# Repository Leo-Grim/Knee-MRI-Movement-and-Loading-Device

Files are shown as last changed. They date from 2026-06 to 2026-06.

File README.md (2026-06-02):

# Repo Overview

This Repository contains all files needed for the construction and assembly of the Device. References are contained in the Final Report.

# Knee-MRI-Movement-and-Loading-Device

A compact, passive, MRI-compatible knee motion and loading device designed for use inside standard closed-bore 3 T MRI scanners.
This project was developed as an Imperial College London Bioengineering group project to enable controlled knee flexion and compressive loading during MRI. The aim is to support imaging of load-dependent knee behaviour, such as cartilage deformation, altered joint contact mechanics, and meniscal extrusion, which may not be visible during conventional unloaded supine MRI.

## Project Overview
Conventional knee MRI is usually performed with the patient lying supine, with the knee unloaded and close to full extension. While this gives high-quality anatomical images, it does not represent the mechanical conditions experienced by the knee during movement or weight-bearing.

This device addresses that limitation by providing:

- Controlled knee flexion using a passive notch-lock mechanism
- Compressive loading through a resistance-band footplate system
- MRI-compatible construction using non-ferromagnetic materials
- Operation inside a standard closed-bore 3 T scanner
- Patient-controlled adjustment using guiding ropes

The prototype is intended as a research platform for future loaded and flexed knee MRI studies.

## Key Features

- Passive mechanical actuation
- No motors, electronics, pneumatics, or ferromagnetic components
- Compatible with closed-bore 3 T MRI environments
- Constructed from PLA and HDPE
- Adjustable knee flexion through discrete notch positions
- Resistance-band-based axial loading
- Low-cost fabrication using FDM 3D printing and CNC machining
- Modular design for future refinement and replication

## Device Concept

The device consists of two main subsystems:

### 1. Movement System

The movement system controls knee flexion. It uses a hinged leg plate and a notch-lock base plate to hold the leg at predefined angles. The user can adjust the knee angle by pulling guide ropes while lying inside the scanner.

### 2. Loading System

The loading system applies compressive force through the foot. A footplate moves along rails against resistance bands, generating a displacement-dependent load. Loading is applied by pushing the footplate to its end position before imaging.

## Materials

The prototype was manufactured from MRI-compatible polymer materials:

- **PLA**: used for 3D-printed components, including hinge parts, rails, notches, backplate, and footplate components
- **HDPE**: used for CNC-machined plate sections due to its flexibility, impact resistance, and machinability

No ferromagnetic, electronic, or closed conductive components are used in the current prototype.

## Fabrication

The prototype was fabricated using:

- Fused deposition modelling 3D printing
- CNC machining of HDPE sheets
- Resistance bands for passive loading
- Polymer-based fasteners and mechanical components where possible

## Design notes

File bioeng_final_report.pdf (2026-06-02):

# DESIGN AND DEVELOPMENT OF AN MRI-COMPATIBLE KNEE MOTION AND LOADING DEVICE

Group ScansOperator

## Department of Bioengineering

## Imperial College London

A Project Report Submitted in Partial Fulfilment of the

Bioengineering Group Project

Supervisor:
Dr P Lally

Department of Bioengineering p.lally@imperial.ac.uk

Word count: 4863
April, 2026

## Jacob Beeson Leonardo Grimaldi Ben Jones Sheena Ling Belle Mok Amy Li Tayeb Tadlaoui Hannah Wei

Abstract

Conventional knee Magnetic Resonance Imaging (MRI) is performed under static, unloaded conditions, limiting detection of load-dependent pathology such as meniscal extrusion, altered cartilage contact mechanics, and early osteoarthritis (OA) progression. Existing dynamic and weight-bearing MRI approaches address this limitation but are constrained by reduced image quality in open-bore systems, or by the complexity, cost, and coil incompatibility of motorised and pneumatic devices designed for closed-bore scanners.
This project aimed to design, fabricate, and validate a compact, passive, MRI-compatible device capable of delivering controlled knee flexion and compressive loading within a standard closed-bore 3 T scanner. The device was constructed entirely from non-ferromagnetic thermoplastics (polylactic acid and high-density polyethylene) using fused deposition modelling and computer numerical control machining. Validation comprised finite element analysis, experimental force-displacement characterisation of a resistance-band loading mechanism, phantom MRI at 3 T, and healthy volunteer usability trials.
The prototype achieved a bench-validated flexion range of 0-117° across five discrete notch-lock positions, with an in-bore range of 0-74° confirmed at 3 T, nearly doubling the ∼40° reported in previous closed-bore devices. The configurable force output of 86-271 N spans the sub-weight-bearing regime in which MRI-detectable cartilage changes have been demonstrated. Phantom imaging confirmed no device-induced artefacts. Volunteer trials also indicated high comfort and perceived safety.
With participant validation and clinical testing, this platform could support earlier detection of load-dependent knee pathology currently undetectable under conventional static imaging.

## 1 Introduction

### 1.1 Clinical and Biomechanical Context

Knee pathologies are a major source of pain, reduced mobility, and long-term disability worldwide, particularly in ageing populations [1]. Osteoarthritis (OA) is the most prevalent musculoskeletal (MSK) disorder, affecting over 500 million individuals globally and most commonly involving the knee [2]. Meniscal tears, ligament injuries, malignancies, and osteomyelitis also contribute to the clinical burden [3].
Mechanical behaviour of the knee is central to the onset and progression of these pathologies. As the largest synovial joint, the knee operates under complex, load-dependent conditions in which contact stresses, joint alignment, and kinematics vary with motion. During routine activities, compressive forces can exceed multiple times body weight (BW), with load distribution mediated by cartilage and meniscal function [4].

### 1.2 MRI for Knee Assessment and Its

Fundamental Limitation

Magnetic Resonance Imaging (MRI) is the primary modality for evaluating soft tissue in the knee due to its high-resolution, multi-planar imaging capability without ionising radiation [5]. It enables imaging of cartilage, menisci, ligaments, and subchondral bone, and thus is widely used in diagnosis and disease monitoring. However, standard MRI is performed with the patient supine, joint unloaded, and typically near full extension. While this configuration optimises image quality and reproducibility, it imposes a crucial limitation: the joint is imaged in a mechanically altered state [6].

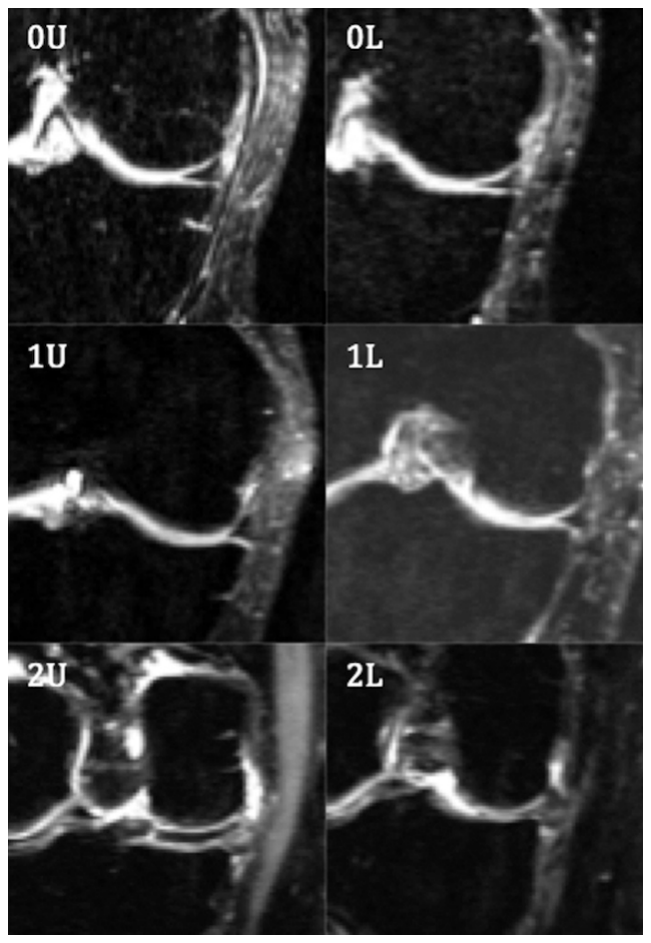
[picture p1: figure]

Figure 1: Coronal MRI of medial menisci under unloaded (U) and loaded (L) conditions in subjects with both increasing radiographic severity (Kellgren–Lawrence score 0–2, top to bottom) and medial meniscal extrusion under loading across all subjects.
Adapted from Patel et al. [7].

As a result, clinically relevant features such as cartilage deformation, tibiofemoral contact mechanics, and meniscal extrusion are either diminished or absent [8], as illustrated in Figure 1, where differences between unloaded and loaded conditions become apparent. This reflects a limitation of the acquisition method rather than imaging resolution. Consequently, an unloaded MRI provides an anatomically accurate but mechanically incomplete representation of the joint, limiting its sensitivity to early or load-dependent pathology.

### 1.3 Existing Approaches to Dynamic Knee

MRIs

To overcome this limitation, dynamic and weight-bearing MRI techniques have been developed to capture joint behaviour under load or motion [4]. These approaches include axial loading systems, which apply compressive forces to the knee, and dynamic imaging systems that induce controlled joint movement during acquisition.
These methods have demonstrated clear benefits, including the ability to reveal load-dependent changes in cartilage contact, joint alignment, and meniscal displacement. However, their clinical applicability is constrained by trade-offs between physiological realism, image quality, and system integration.
Open-bore MRI systems have been widely used in such studies for their larger geometry, which accommodates upright or partially weight-bearing postures and external loading apparatus (Figure 2). However, they operate at lower field strengths (0.2–1.0 T), reducing signalto-noise ratio (SNR) and spatial resolution compared to high-field (1.5–3.0 T) closed-bore scanners [9, 10], limiting detection of subtle structural changes in early disease.

Figure 2: Open-bore MRI setup for weight-bearing joint imaging. Adapted from Draper et al. [11].

Closed-bore dynamic MRI systems preserve image quality but face other limitations. External rigs are bulky and difficult to integrate within the confined bore, while motorised actuation introduces electromagnetic interference (EMI) and ferromagnetic safety risks, and pneumatic systems require complex external infrastructure [12]. The Brisson et al. device [13] (Figure 3) achieved guided flexion up to ∼40° via a beltdriven motorised pneumatic system, but required external motor hardware, a custom gearbox, and flexible surface coils in place of a standard knee coil.

Figure 3: Example of a motorised closed-bore knee motion and loading device. Left: 3D rendering of the device assembly. Right: the device in a 3 T scanner with a subject. Reproduced from Brisson et al. [13] under CC BY-NC-ND 4.0 licence.

Even compact axial loading devices for supine imaging provide only partial solutions, replicating compressive loading but lacking controlled joint motion across a range of flexion. Existing approaches therefore either sacrifice imaging quality, mechanical fidelity, or clinical integration.

### 1.4 Engineering Constraints in

Closed-Bore MRI

The development of any device intended for use within an MRI environment is constrained by strict safety, material, and geometric requirements. Strong static magnetic fields, time-varying gradients, and radiofrequency (RF) energy impose limitations on both material selection and actuation strategies.
According to established safety guidance [14], ferromagnetic materials must be excluded due to projectile and torque risks, while conductive materials must be minimised to avoid RF-induced heating and imaging artefacts. These constraints favour the use of polymer-based materials and non-magnetic components, but introduce challenges in achieving sufficient mechanical strength and durability.
Beyond material requirements, closed-bore MRI systems impose significant geometric limitations, restricting available space to a bore diameter of 60–70 cm. Any device must therefore be compact, compatible with coil placement, and allow for patient positioning. Electrically driven systems are generally unsuitable due to EMI and safety concerns [12]. Consequently, mechanical systems provide a more viable approach, but must be capable of delivering controlled, repeatable motion without active feedback or external control systems.
These combined constraints define a tightly bounded design space in which mechanical functionality, MRI compatibility, and clinical usability must be simultaneously satisfied.

### 1.5 Research Gap, Objectives and

Hypothesis

Despite the development of dynamic and weight-bearing techniques, no widely adopted solution currently exists. Such an ideal system should enable controlled and repeatable knee motion and loading within a standard high-field closed-bore MRI environment without compromising image quality, safety, or simplicity.
This study addresses this gap through the design and development of a compact, passive, mechanical, MRI-compatible knee loading and motion device intended to enable diagnostic imaging under physiologically relevant loading within a closed-bore scanner. Functional daily activities require less than 90° of knee flexion for level walking, and 90-120° for stair negotiation and chair use [15], with tibiofemoral compressive forces ranging from ∼107% BW (∼735 N) during bilateral stance to over ∼346% BW (∼2,376 N) during stair descent for a 70 kg individual [16]. Reproducing such ambulatory forces within a closed-bore scanner is neither practical nor necessary for diagnostic purposes, as MRI-detectable tissue changes have been demonstrated at substantially lower, sub-weight-bearing loads. Sub-weight-bearing loads of ∼50% BW (∼350 N at 20° flexion) represent the most widely validated loading protocol, producing significant decreases in cartilage T1ρ (spin-lattice relaxation in the rotating frame) and T2 (spin-spin relaxation) times, both sensitive to early compositional changes in cartilage matrix, and increased meniscal extrusion at 3 T [17, 18]. In vivo T1ρ changes have been detected at loads as low as 20 kg (∼196 N) in the patellofemoral joint [19], and ex vivo compartmental loading has revealed significant cartilage responses from 73.5 N [20]. A device operating within this sub-weight-bearing regime could therefore be sufficient to elicit diagnostically relevant tissue responses without approaching full ambulatory loads.
Regarding flexion, the range over which diagnostically useful images can be acquired within a closed-bore scanner is more restricted, as increasing flexion displaces the knee from the magnetic isocentre and reduces image quality. Existing closed-bore devices have been limited to ∼40° due to the geometric constraints of a typical 60–70 cm bore diameter [13]. This study ideally targets a flexion range of 0 to 90°, subject to the geometric constraints of the scanner.
The specific objectives are, therefore, to:
1. Develop a passive mechanical system enabling controlled knee flexion over an ideal range of 0-90° with discrete angular positioning [9, 21].
2. Deliver compressive loading within the sub-weight-bearing regime, with forces approaching or exceeding the ∼200 N threshold at which in vivo T1ρ changes have been demonstrated [19], ideally reaching the ∼350 N (50% BW) level used in most published loading protocols [17, 18, 22].
3. Quantify | the | repeatability | of | the | force-
displacement response.
4. Ensure full compliance with MRI safety and material constraints.
It is hypothesised that a passive, non-ferromagnetic mechanical system can achieve controlled and repeatable knee motion within MRI constraints without introducing imaging artefacts or compromising patient safety. Validation of this hypothesis would demonstrate the feasibility of integrating such a device into clinical studies aimed at assessing load-dependent knee biomechanics.

## 2 Methods

### 2.1 Concept Development, Selection and

Design

The design was divided into two subsystems, movement and loading, to allow parallel development and to achieve defined objectives.

### 2.1.1 Movement System Design

Figure 4: Design of the movement component, with leg-plate configurations for different knee angles, 0° (left), 45° (centre), 90° (right).

A patient-controlled mechanism was selected, incorporating guiding ropes, a leg-plate, and leg-plate stoppers. This enabled user adjustment, repeatable stable positioning at predefined angles, minimised the need for radiographer intervention, and maintained MRI compatibility. Device flexion angle was defined as the angle between the thigh-plate and calf-plate axes at the hinge joint (Figure 5), corresponding anatomically to the angle between the femoral and tibial axes when the limb rests along the respective plates.

Figure 5: Definition of the device flexion angle. The blue line represents the thigh-plate axis, the red line represents the calf-plate axis, and the yellow arc indicates the flexion angle at the knee.

### 2.1.2 Loading System Design

Figure 6: CAD design of the loading component; red boxes indicate attachment points for resistance bands, red arrows indicate direction of footplate travel and foot pushing (increasing left to right)

A resistance-band loading mechanism was selected as a lightweight, non-ferromagnetic solution for generating force. As shown in Figure 6, the system consisted of a footplate, through which compressive load was transmitted along the lower limb, and a backplate, which functioned as structural support. Resistance bands were anchored between the fixed baseplate and the footplate, generating a displacement-dependent force that increased with footplate travel.

Figure 7: Open-source planetary gear wheels used for Loading System.

The footplate was translated by eight wheels that rolled along rails within the backplate, using an open-source planetary gear wheel design, shown in Figure 7, to minimise friction between moving components, a difficulty noted in previous mechanical systems [23].

### 2.1.3 Final Design

Figure 8: Integration of the loading and movement systems. The red arrow indicates the direction of footplate travel, and the yellow arrow indicates the direction of rope pulling to increase angle.

To integrate the subsystems, the loading component was mounted at the distal end of the leg-plate, shown in Figure 8. Imaging would occur at maximum footplate displacement of 20 cm, corresponding to contact between the footplate and backplate. Scans would be repeated at predefined knee angles using the usercontrolled movement system for sequential image acquisition.

### 2.2 Material Selection

Parameter | Value | Unit
Layer orientation | Flat | –
Raster angle | 0/90 | °
Layer height | 0.1 | mm
Infill density | 15% | –
Infill pattern | Rectilinear | –

Table 1: Key 3D printing FDM process parameters used.

Polymer-based materials were selected to ensure MRI safety [14], and evaluated against processing complexity and mechanical reliability across the required range of motion.
PLA was selected due to its dimensional stability during fused deposition modelling (FDM) [24]. The anisotropic properties of FDM-made parts were accounted for through component orientation with FDM parameters defined in Table 1. Alternative materials were eliminated due to processing complexity and limited accessibility.
HDPE was selected due to its impact resistance, flexibility, and cost [25]. HDPE was purchased in sheet form, enabling simple and reliable fabrication. Secondary sustainability benefits included PLA’s renewable origin [26] and HDPE’s recyclability [27].

### 2.3 CAD Modelling, Iterative Design, and

Prototype Fabrication

The movement and loading systems were developed through an iterative computer-aided design (CAD), simulation, and fabrication process. Finite element analysis (FEA) and physical prototyping were conducted in parallel on load-bearing components, with high-stress regions identified and refined. Iterative updates were applied to improve structural integrity and usability.

### 2.3.1 Fabrication of Movement Component

Figure 9: Earlier iteration of the movement component CAD model that informed the final fabrication strategy.

The movement component was manufactured using a combination of FDM and computer numerical control (CNC) machining. The hinge joints, base plate notches, and rails were manufactured through FDM in PLA, allowing rapid iteration of the more complex components. The larger plate sections were CNCmachined from HDPE sheets.

### 2.3.2 Fabrication of Loading Component

Figure 10: CAD models of Backplate with screw holes shown (left) and Footplate (right), before attachment and inclusion of wheels and other components.

The loading component was manufactured by FDM in PLA. It consisted of two sub-assemblies: the backplate and the footplate, shown in Figure 10. The final backplate and footplate designs could each be printed as single parts on a 3D printer (FDM). The final design also included screw holes for attachment to the movement component.

### 2.4 Risk Assessment and Safety

Considerations

A structured risk assessment conducted on key risks, their likelihood, severity, and mitigation strategies, is summarised in Table 2.

Risk | Description | L | S | Mitigation | Contingency
MRI Safety | Component not MRI-safe | Low | High | Non-ferromagnetic ma-terial selection, magnet testing of components, device-only MRI dry run | Remove or replace unsafe components
Mechanical Failure | Structural failure or insufficient force | Med | Med | FEA with safety factors, incremental loading during testing, spare parts avail-able | Redesign and reprint com-ponents
Patient Safety | Pain or unsafe knee motion | Med | High | Patient-controlled motion, motion limits, padding and adjustable supports | Reduce motion range; use patient-driven movement only
Schedule | Delays in fabrica-tion or testing | Med | Med | Built-in time buffers, paral-lel task allocation, backup fabrication options | Scope reduction if required

Table 2: Risk assessment for device development. L = Likelihood, S = Severity; ratings: Low, Medium (Med), High.

### 2.5 Operation of Device inside the

Scanner

Figure 11: Series of images displaying the initial position of the device (left), insertion of foot and pushing against footplate (centre), and pulling ropes to change knee angle (right).

Device operation is patient-controlled and supported by a radiographer using the scanner communication system. A user manual was developed for radiographer training and user operation (Appendix F). During imaging, the patient lies supine, with one leg positioned on the movement component, the foot placed against the loading footplate. Compressive load is applied by pushing the footplate to its maximum displacement (in contact with the baseplate), after which an MRI is acquired at predefined knee angles. Between scans, the patient adjusts the flexion angle by pulling the guiding ropes until reaching the next notch-lock position, then reapplies load before the next acquisition (Figure 11).

### 2.6 Testing and Validation Methodology

This validation process aimed to determine whether the device could generate and sustain controlled and repeatable compressive loads.

### 2.6.1 Computational Analysis

All components were evaluated through computational analysis using FEA in Ansys Mechanical [28]. Deformation and stress analyses were performed to identify critical stress concentrations across the assembly under load (Appendix C). The mesh was subsequently refined in high-stress regions to improve simulation accuracy and better distribute the load across the structure. Insights from each analysis were used to inform iterative improvements to the CAD models, allowing structural weaknesses to be addressed before fabrication.

### 2.6.2 Resistance Band Testing

Figure 12: Digital dynamometer with hook used to analyse resistance band force profile (left), with unfolded (centre) and folded (right) resistance band configurations.

Force-displacement tests were used to characterise the mechanical behaviour of the resistance-band loading system and assess its suitability for force generation. A digital dynamometer was used to record force at controlled displacements of the resistance band under two configurations: unfolded and folded, shown in Figure 12. A 1.1 mm, 30 cm Internal Diameter Latex resistance band was used. The unfolded configuration represented a single band segment, while the folded configuration represented the band doubled back to produce a shorter load path and higher resistance. For the unfolded configuration, displacement was increased in 1 cm increments (1 − 15 cm). For the folded configuration, displacement was increased in 0.5 cm increments (0.5−7.5 cm). Five measurements were taken at each displacement. The data were then analysed, and the two configurations were compared using the code in Appendix E.

### 2.6.3 MRI In-Bore Testing

The device was tested in a 3 T MRI scanner using a water-filled phantom positioned at the knee location. A large 4-channel flexible coil was placed around the phantom and device to replicate the intended imaging configuration (Figure 13). Acquisition parameters are summarised in Table 3. The device was scanned at 0° to confirm the absence of imaging artefacts, and the maximum in-bore flexion angle was determined by advancing the movement component through its notch-lock positions until bore geometry prevented further flexion.

Parameter | Value
Scanner | Siemens Magnetom Verio 3 T
Sequence | PD TSE (sagittal)
Acquisition time | 3 min 34 s
Voxel size | 0.6 × 0.6 × 3.0 mm
TR / TE | 5300 / 36.0 ms
Flip angle | 150°
Turbo factor | 10
Slices | 35
FOV | 240 mm
Coil | Large 4-channel flex coil

Table 3: MRI acquisition parameters for in-bore phantom testing.

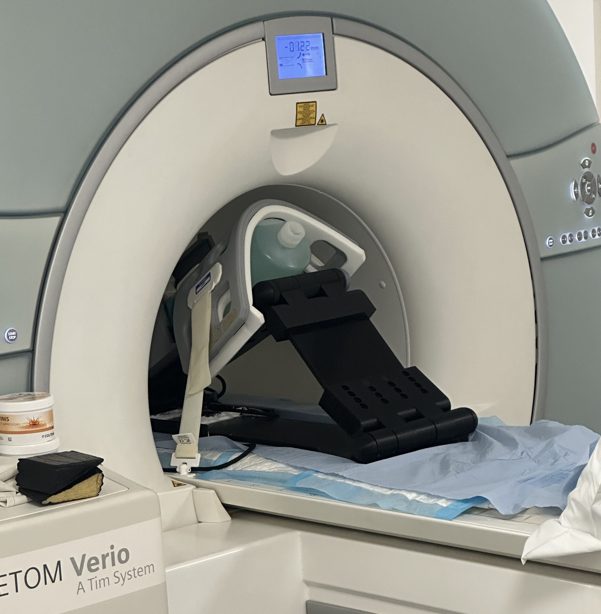
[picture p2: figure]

Figure 13: Device positioned within the Siemens Magnetom Verio 3 T scanner bore at the maximum in-bore flexion angle (74°), with the water-filled phantom and large 4-channel flexible coil in place.

## 3 Results

### 3.1 Finite Element Analysis

Property | PLA | HDPE | Unit
Density | 1240 | 970 | kg/m³
Young’s Modulus | 3.5 | 1.1 | GPa
Poisson’s Ratio | 0.36 | 0.45 | –
Yield Strength | 50 | 23.6 | MPa
UTS | 65 | 45 | MPa
Shear Modulus | 1.29 | 0.75 | GPa

Table 4: Material properties of PLA and HDPE at 25°C (UTS is Ultimate Tensile Strength).

FEA was performed on each prototype iteration of both the loading and movement components, using PLA and HDPE material properties (Table 4).

### 3.1.1 Loading Component

62.4 N was applied to the load-bearing components, corresponding to the single unfolded band configuration at the tested displacement range, then doubled to give a safety factor of 2. Higher-stiffness band configurations (up to 271 N projected, Table 6) were therefore not explicitly simulated and would require additional FEA verification. The resulting stress distributions and deformation profiles were used to identify specific regions of weakness.

### 3.1.2 Movement Component

Downward forces were applied as the primary load case, set at ∼314 N, 100% greater than the average weight of the human leg (∼16 kg, 157 N).

Figure 14: Ansys simulations of stress of final design under a downward force of 314 N.

Early prototypes exhibited excessive deflection and localised stress under load, prompting redesign and a transition to HDPE in some components. FEA of the final design yielded a peak von Mises stress of 3.42 MPa and maximum deformation of 0.36 mm under 314 N loading, both well within HDPE’s yield strength of 26 MPa. Hinge joints were redesigned to prevent structural failure under load, and for the final design, a stopper was added to the end of the calf plate to support the peak stress seen in the final design in Figure 14.

### 3.2 Angular Positioning

The movement component achieved stable positioning at five flexion angles, corresponding to the notch-lock positions along the base plate. Angles were determined from triplicate measurements on photographs of the device at each notch-lock position using ImageJ [29], with a measurement uncertainty of ±1°. The measured on-bench angles were 0°, 37°, 74°, 93°, and 117° (Figure 15), spanning from full extension to maximum flexion of 117°.

Figure 15: Composite overlay of the movement component at all device angles, from 0°-117°.

### 3.3 Force-Displacement Analysis of

Resistance Bands

### 3.3.1 Force-Displacement Response

For the loading mechanism, force-displacement behaviour was characterised in unfolded and folded configurations.

Figure 16: Mean force-displacement response of the resistance band in unfolded and folded configurations, shown with 95% confidence intervals (CI).

The folded band produced higher force than the unfolded band across the tested range, as seen in Figure 16 consistent with increased effective stiffness in the doubled-band configuration.

### 3.3.2 Stiffness and Model Fitting

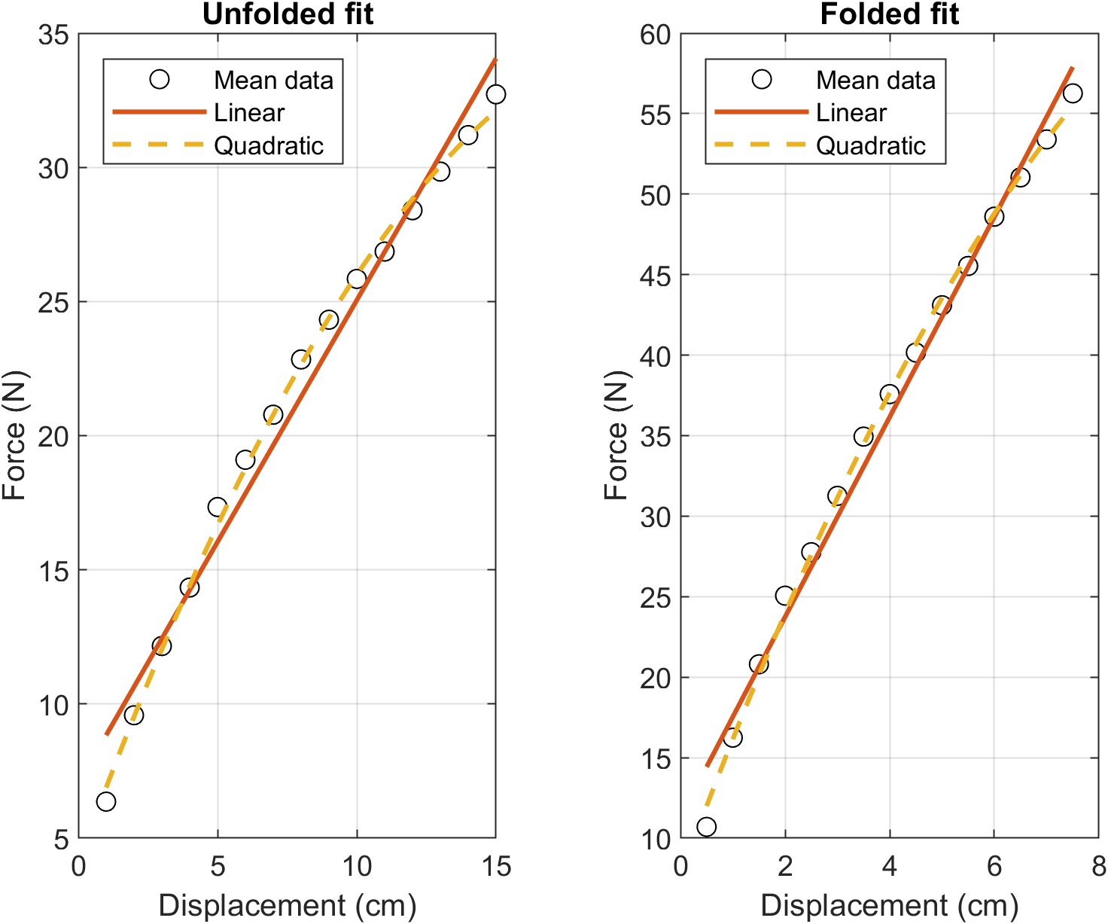
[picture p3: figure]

Figure 17: Linear and quadratic fits to the mean force-displacement data for unfolded and folded resistance band configurations.

Parameter | Unfolded | Folded
Max mean force (N) | 32.72 | 56.26
Max displacement (cm) | 15.0 | 7.5
Global stiffness (N/cm) | 1.802 | 6.211
Best model | Quadratic | Quadratic
Adjusted R² | 0.9976 | 0.9977
CV (High-Low) | 13.8-4.56% | 15.97-2.46%
AIC (High-Low) | 50.07-17.57 | 57.84-32.93

Table 5: Summary of key force-displacement results for the resistance band configurations, CV is the Coefficient of Variation and AIC is the Akaike Information Criterion.

Linear regression showed a strong force-displacement relationship for both configurations, but quadratic models provided the best fit, as can be noted in Figure 17. The unfolded configuration, detailed in Table 5, gave a global stiffness of 1.802 N/cm, while for the folded configuration the stiffness was 6.211 N/cm. The folded configuration was therefore ∼3.4 times stiffer than the unfolded configuration.
Quadratic fitting described the data more accurately than linear fitting, confirmed by mild non-linearity in the band response [30, 31, 32].

### 3.3.3 Repeatability of Band Loading

The repeated trials showed good consistency for both configurations. The trend of CVs in Table 5 indicates that measurement variability was greatest at the smallest extensions, where the force was lowest, but improved as the band was stretched further [30]. This is useful as imaging will occur beyond the maximum tested extension.

### 3.3.4 Comparison of Folded and Unfolded

Configurations

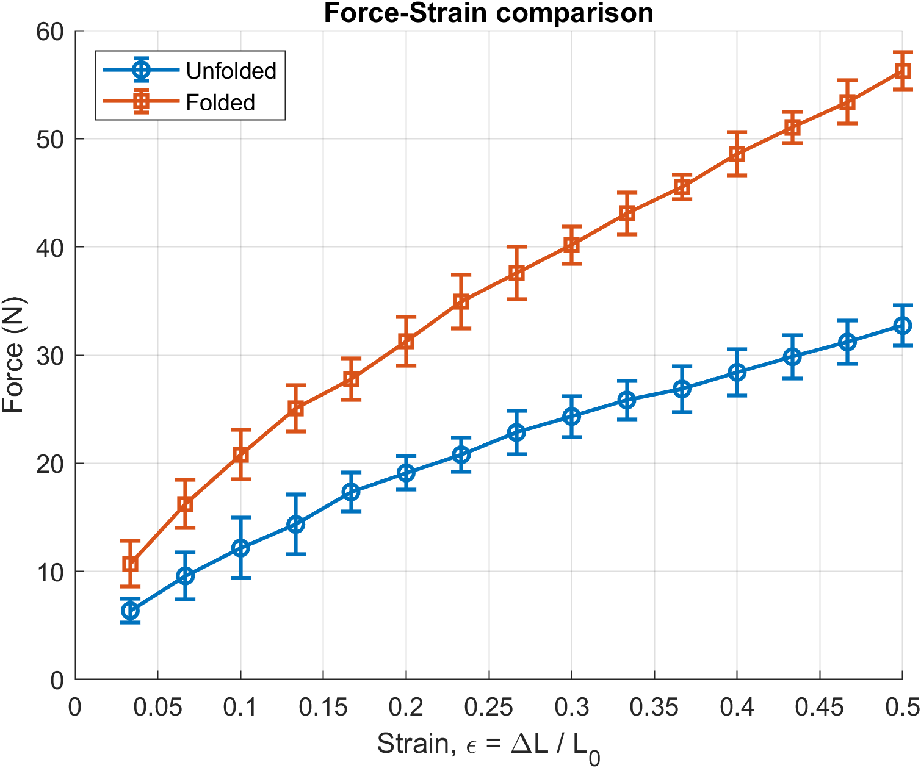
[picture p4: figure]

Figure 18: Force-strain comparison for the resistance band in unfolded and folded configurations, shown with 95% confidence intervals.

To compare the two configurations more rigorously, force was also analysed against strain ε = ∆L/L0. As is shown in Figure 18, performing the resistance-band fold provided a clear difference in load output at matching strain.

### 3.3.5 Maximum Force Extrapolation

Imaging was intended to occur after 20 cm of footplate travel. Since this displacement lies outside the measured range, estimating the load at this point required extrapolation. Although the quadratic model gave the best fit, the linear model was used because it is the more conservative and physically reasonable choice beyond the measured data [31].

Parameter | Unfolded | Folded
1 band Fˆmax(N) | 43.1 | 135.5
2 parallel band Fˆmax (N) | 86.1 | 271.1

Table 6: Projected force at 20 cm footplate travel using the linear force-displacement models for 1 and 2 band configurations.

The linear models predicted a force of 43.1 N for a single unfolded band and 135.5 N for a single folded band at 20 cm displacement, as shown in Table 6. This again indicates higher maximum compressive loading for the folded configuration.

### 3.4 In-Bore Artefact and Distortion

Screening

Phantom imaging using the PD TSE protocol (Table 3) at 0°, with the device positioned near the magnetic isocentre, produced no visible artefacts, signal voids, or geometric distortion (Figure 19, left). At higher flexion angles, geometric distortion was observed (Figure 19, right), increasing progressively with distance from the isocentre regardless of device orientation, consistent with inherent B0 field inhomogeneity rather than device-induced effects. The device has therefore proved not to introduce artefacts at 3 T.
The device alone could be accommodated at all five notch-lock positions within the bore. With a leg positioned on the device, the maximum achievable flexion was 74° (third notch-lock position), beyond which the combined geometry exceeded bore clearance. On-bench and in-bore ranges are summarised in Table 7.
Position | Angle | Increment | In-bore
| (°) | (°) | (with leg)
1 | 0 | – | Yes
2 | 37 | 37 | Yes
3 | 74 | 37 | Yes (maximum)
4 | 93 | 19 | No
5 | 117 | 24 | No

Table 7: Discrete device angular positions measured with angles and in-bore fit in a Siemens Verio 3 T scanner (70 cm bore).

Figure 19: Sagittal PD TSE images of the phantom. (Left) At 0° flexion near the magnetic isocentre. (Right) At 74° flexion.

### 3.5 Healthy Volunteer Trials

Metric | Score (/10)
Overall comfort | 8.90 ± 1.0
Perceived safety | 9.90 ± 0.4
Comfort of holding loaded | 9.38 ± 0.7
position (5–10 min)
Resistance to slipping | 6.25 ± 2.3
Smoothness of movement | 7.60 ± 1.1

Table 8: Human factors questionnaire results for eight healthy volunteers (mean ± SD)

Eight female volunteers aged 18-22 were recruited to evaluate the human factors of the device. Ethical approval was not required for this preliminary usability study as no clinical procedures were performed; all participants provided written informed consent and were screened for current knee pain, with those presenting active symptoms excluded. A questionnaire (Appendix

D) was completed following the trial, scored 1–10; results are summarised in Table 8. No volunteer reported pain during use.

## 4 Discussion

This project hypothesised that a passive, non-ferromagnetic device could achieve controlled and repeatable knee motion within MRI constraints without compromising safety or image quality. The final prototype achieved a bench-validated flexion range of 0 − 117° across five discrete notch-lock positions, with an in-bore range of 0 − 74° confirmed at 3 T, a configurable loading range of ∼ 86−271 N (Table 6) spanning from below to above the ∼200 N threshold at which in vivo T1ρ changes have been reported [19], and artefact-free phantom imaging at 3 T. Results support this hypothesis, though full confirmation requires in-scanner testing with a participant under operational loading conditions.

### 4.1 Mechanical Validation and Device

Performance

Iterative FEA validated structural integrity across all load cases, with peak stresses below the yield limits of PLA and HDPE. However, these simulations assumed homogeneous, isotropic material properties. PLA components fabricated via FDM exhibit anisotropic mechanical behaviour due to layer-by-layer construction [33], so actual failure thresholds may be lower, especially at inter-layer boundaries. Physical load-tofailure testing is required to confirm safety margins. The force output (Table 6, Figure 20) represents ∼ 8−19% of typical ambulatory tibiofemoral loading [16], spanning from the lowest ex vivo detection threshold (∼73.5 N [20]) up to near the ∼350 N (∼50% BW) clinical gold standard [17, 18, 22].
While this falls below full weight-bearing, comparable force magnitudes have been reported to produce measurable changes in cartilage contact area, relaxation times and meniscal displacement during MRI [17, 34, 18]. Whether the device can elicit similar tissue responses under loaded imaging conditions remains to be confirmed through participant testing.
Healthy volunteer trials showed 8.9/10 comfort and 9.9/10 perceived safety, with no reported pain and all participants indicating willingness to undergo scans with the device. These results support mechanical performance, as stationary positioning is required during sustained MRI loading and discomfort or instability would produce motion artefacts [35]. Volunteers rated the ability to hold a loaded position for 5 − 10 minutes at 9.375/10. The PD TSE protocol required 3 minutes 34 seconds per acquisition (Table 3), and diagnostic T1ρ and T2 mapping sequences typically take 9 − 11 minutes [13, 36]. Both durations fall within the tested comfort tolerance, suggesting patient com-

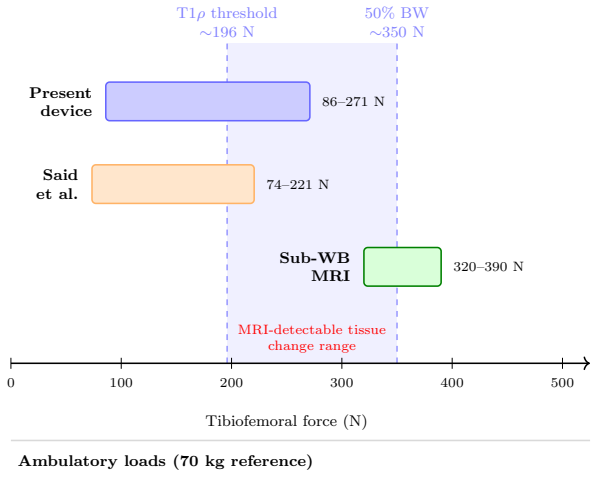
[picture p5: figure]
T1ρ threshold ∼196 N; MRI-detectable tissue change range; Present; device; Said; Sub-WB; MRI; Tibiofemoral force (N); Ambulatory loads (70 kg reference)

Two-leg stance | 735 N | (107% BW)
Walking | 1,792 N | (261% BW)
Stair ascent/descent | 2,170–2,376 N | (316–346% BW)

Figure 20: Force output of the present device. Shaded region indicates the range from the in vivo T1ρ detection threshold (∼196 N [19]) to the 50% BW gold standard (∼350 N [17]). Sub-WB MRI refers to forces applied by Souza et al., Scott et al. and Jogi et al. [17, 34, 22]. Ambulatory benchmarks are for a 70 kg reference person [16].

pliance is unlikely to be a limiting factor. However, resistance to slipping (6.25/10) and smoothness of angular adjustment (7.6/10) identified positional stability and angular control as functional limitations, informing the planned design refinements. Qualitative post-trial feedback supported these findings.
Planned refinements include improved stability (increasing wall height and elevating the base hinge), finer notch spacing, adjustable rope tension, additional padding, and a rapid-release mechanism to properly account for the obtained data.

### 4.2 Measurement Reliability and

Uncertainty

The coefficient of variation (CV) was highest at small displacements (15.97% folded, 13.8% unfolded) where low absolute forces amplified measurement errors, and fell to 2.46% and 4.56% at maximum tested displacements (Table 5). Since imaging occurs at 20 cm of footplate travel, beyond the tested range, the mechanism operates in its most repeatable regime during use.
Extrapolation to the imaging position introduces uncertainty. The quadratic model fitted the tested range best (Figure 17), but the linear model was selected for projection as the more conservative basis [31]. The projected 271 N maximum (Table 6) should therefore be treated as an estimate rather than a validated operating load, pending extended-range testing.
The volunteer trials carry methodological limitations.

The small, young, female sample is demographically distant from the target OA population, older adults with reduced quadriceps strength, restricted range of motion, and altered joint geometry [37], meaning usability findings cannot be directly extrapolated to clinical use. The questionnaire was study-specific rather than a validated instrument. The slipping risk score (6.25 ± 2.3/10) was influenced by an outlier of 1/10, with the remaining seven volunteers scoring 5 to 8, suggesting an isolated experience rather than systematic weakness, though the concern warrants investigation regardless.

### 4.3 MRI Compatibility

The device uses no ferromagnetic, electronic, or closed conductive components and is built from lowsusceptibility PLA/HDPE. Fully passive actuation avoids the EMI risks of motorised alternatives and the infrastructure complexity of pneumatic systems [38], while its compact geometry requires no scanner modifications.
Phantom imaging at 0° near the magnetic isocentre confirmed that the assembled device did not introduce artefacts, signal voids, or geometric distortion at 3 T, empirically validating MRI compatibility beyond the initial material-based classification. Geometric distortion observed at higher flexion angles, where the phantom was displaced from the isocentre, is consistent with inherent B0 inhomogeneity in closed-bore scanners [39] rather than a device-induced effect. Formal evaluation to ASTM standards [40, 41] is required before clinical use.

### 4.4 Comparison with Existing Approaches

Table 9 compares the present device with existing MRI-compatible knee loading systems. Pneumatic systems deliver sustained, precisely controlled forces validated in cadaveric specimens [20], while motorised platforms support continuous cyclic loading with real-time angular monitoring [13]. By contrast, the present passive design is limited to quasi-static loading without real-time in-bore force measurements.
However, both have barriers to adoption: pneumatic systems require compressed gas infrastructure and external controls, while motorised platforms involve complex external assemblies [13], potentially precluding standard multi-channel knee coils. The present device addresses these constraints through: passive actuation, no external infrastructure requirements, compact geometry accommodated by a large 4-channel flexible coil, and low-cost 3D FDM printing and CNC fabrication. Its modular design allows adjustment for different limb lengths, independent fabrication of components, and future interchangeable notch plates for application-specific angular increments, lowering the barrier for replication by other research groups.
The maximum predicted force output (271 N with two folded bands, Table 6) is substantially lower than full ambulatory loading (up to 346% BW during stair descent [16]), but as established in Section 1.5, reproducing such forces is not necessary for diagnostic purposes. The device operates in a sub-weight-bearing regime with detectable MRI tissue changes, prioritising accessibility over load capacity. Load range is defined by resistance bands, not structural limits; stiffer bands can reach the ∼350 N gold standard with no redesign. Among passive systems, the device reported by Jogi et al. demonstrated artefact-free axial loading using an elastic string between a waist belt and footplate, though its calibration resolution was limited to 2 kg steps due to overlapping force-displacement values at finer increments [22]. The most directly comparable design, which also employed elastic resistance via a footplate mechanism [23], reported significant measurement variability by friction in the footplate-axis interface. This device’s notch-lock design and folded bands deliver low-variability loading (Table 5), suggesting these specific mechanical issues have been mitigated, though a direct side-by-side comparison was not performed.

### 4.5 Clinical Relevance, Limitations and

Future Directions

The primary clinical motivation is the gap in conventional static MRI, where load-dependent phenomena may remain undetected [9, 4]. By enabling controlled compressive loading within a standard closed-bore scanner, the device provides a platform to investigate these biomechanical changes under conditions closer to physiological weight-bearing. Detecting such changes under load could directly inform clinical decision-making, e.g. by revealing meniscal instability or cartilage insufficiency that would alter suitability for surgery or treatment selection but remains invisible on conventional static sequences [42]. Beyond diagnostics, such measurements could support empirical validation of computational biomechanical models currently reliant on indirect gait-analysis estimates [43]. The lowered barrier to loaded knee MRI for specialist facilities supports broader clinical and research adoption. However, several critical limitations must be addressed before adoption. Validation was conducted exclusively with healthy volunteers aged 18 − 22; patients with knee pathologies may present with restricted range of motion, altered joint geometry and reduced muscle strength, which could affect device performance in ways not captured by the current dataset [37]. Although phantom testing confirmed MRI compatibility and an in-bore flexion range of 74°, participant testing has not yet been completed, meaning the device’s performance under real imaging workflows, including the ability to maintain positioning throughout a full acquisition sequence, remains unconfirmed. The bench-validated flexion range of 0 − 117° exceeds the 90° tar-

Feature | Said et al. [20] | Brisson et al.
[13]
Jogi et al. [22] | Buur [23] | Present | de-
| | | | | vice
Actuation | Pneumatic | Motorised
| | pneumatic | Passive (elastic
| | | string)
Passive | (elas-
| | | | tic)

Passive (elastic
bands)
Loading mode | Varus–valgus | Flexion–
extension | ±
| | axial | Axial via foot-
| | | plate | Axial via foot-
| | | | plate

Axial via foot-
| | | | | plate
Force range | 73.5–220.6 N | Up to ∼27 Nm | ∼50% | BW
| | | (∼320–390 N)
Not reported | 86–271 N
Flexion capability | Fixed | 0–40° | Fixed | (ex-
| | | tended)
Adjustable | 0–117° | on-
bench, | 0–74°
in-bore
Standard knee coil | No | No | Yes | Yes | No | (4-channel
flex coil)
External infrastructure | Compressed
gas, | control
| unit
Motor, | gear-
| | box, belt drive | None | None | None
MRI validation | 3 T (cadaveric) | 3 T (in vivo) | 0.25 T and 3 T (in vivo)
Prototype only | 3 T (phantom)

Table 9: Comparison of the present device with existing MRI-compatible knee loading systems.

get, but in-bore testing confirmed a maximum of 74°
(third notch-lock position) before bore clearance was
exceeded. This nearly doubles the ∼40° reported by Brisson et al. [13] in a comparable bore, likely due to the compact footprint and absence of external mechanical hardware. Notably, residual bore clearance was observed at 74°, indicating that the true geometric limit lies between 74° and 93° (the next fixed notch position). The current fixed notch spacing therefore leaves usable bore space unexploited. Extending the existing modular design philosophy to the notch plate itself, by replacing fixed positions with a slideable, clippable system, would allow continuous angular positioning within the in-bore range, both recovering this lost capacity and enabling finer angular resolution between 0° and the true geometric maximum. However, increasing flexion displaces the knee from the magnetic isocentre, where B0 homogeneity and gradient linearity are optimal [39]. The geometric distortion observed at higher flexion angles during phantom testing was attributable to this inherent scanner characteristic rather than the device itself (Section 4.3), but may nonetheless degrade quantitative measurements such as T1ρ and T2 relaxation times at the upper end of the in-bore range. This off-isocentre distortion is a well-characterised limitation of closed-bore MRI, arising from gradient nonlinearity that increases with distance from the isocentre [44], and clinical scanners typically include vendor-implemented nonlinearity correction based on spherical harmonic field models [45]. Additionally, images acquired at 0° near the isocentre could serve as an undistorted spatial reference against which higher-angle acquisitions are registered, enabling further post-acquisition geometric correction. Even if the usable in-bore range is restricted to lower flexion angles, these correspond to the stance and early flexion phases of gait where tibiofemoral compressive forces are highest [16] and where load-dependent cartilage and meniscal changes are most clinically relevant for early disease detection [17, 18]. The device therefore retains diagnostic utility even under significant boreimposed angular constraints. Furthermore, the force at the intended imaging position is extrapolated beyond the tested range, and the FEA-predicted structural margins have not been verified through physical load-to-failure testing.
Planned design refinements, informed by feedback, target the functional weaknesses identified in trials, including improved positional stability, finer angular increments and an integrated rapid-release mechanism as required for any device used within an MRI bore. The PD TSE sequence provides morphological assessment but does not capture the compositional changes (proteoglycan loss, collagen disorganisation) detectable through quantitative T1ρ and T2 mapping. Future protocols should incorporate these sequences, which require longer acquisition times (9 − 11 minutes [36, 46]) but remain within the volunteer-tested comfort tolerance. As a prerequisite, in-scanner validation with participants requires formal ethics approval, an application for which is planned following submission, to confirm device performance under operational loading conditions with a leg in the device. Following this, validation should be extended to patient cohorts, with an initial feasibility study comparing symptomatic OA patients and age-matched controls to determine whether the achievable loading range can detect clinically meaningful differences in cartilage and meniscal behaviour [47, 19].
New reporting criteria are also required, with radiologists requiring clear parameters for comparing unloaded and loaded acquisitions. Radiographers will require more detailed training protocols to ensure reproducible knee positioning at the scanner isocentre for

high-quality imaging.
To facilitate adoption by other research groups, the full CAD files and technical drawings (Appendix B) will be made available. The device was fabricated at an estimated material cost of ∼£175 using commercially available products, with all structural components produced by desktop FDM 3D printing and CNC machining (Appendix G).

Conclusion

This project designed, fabricated and validated a compact, passive, MRI-compatible knee loading device for use within standard closed-bore scanners. The prototype achieved a bench-validated flexion range of 0 − 117° and an in-bore range of 0−74° at 3 T, nearly double the ∼40° reported in previous closed-bore devices, with a configurable force output of ∼ 86−271 N spanning the sub-weight-bearing regime relevant to cartilage assessment. Phantom imaging confirmed MRI compatibility with no device-induced artefacts. With participant validation and clinical testing, the platform could support earlier detection of load-dependent pathology currently invisible under static imaging conditions.

## Appendix

Appendix A: Project Management Assessment

Deviations from Project Planning
Following the Project Pitch, the project has continued along the direction outlined in the presentation. The latest prototype of the device was completed after the CAD design, fabrication, testing, and assembly stages were finished. As noted in the pitch, extra time was intentionally left for further design improvements based on feedback from researchers and peers. At this stage, that feedback has been acknowledged but has only been incorporated as considerations in the report rather than implemented in the prototype itself. However, it will inform the development of a new prototype in the coming months.

Project Management lessons
Project Management lesson 1: During the initial design phase of the project, several techniques were considered for both the movement and loading mechanisms. This analysis was important, as it provided one of the main sources of data and comparison across the different design iterations. However, the literature described many potential techniques that could have been incorporated into the device, which made the selection process particularly challenging, especially given the MRI constraints. As a result, a significant amount of time was devoted to identifying the most suitable approach, which ultimately reduced the time available for the CAD design and fabrication phase. In future, it would be advisable to begin the design selection process earlier and to hold more frequent meetings to discuss and eliminate infeasible techniques, thereby accelerating the process.
Project Management lesson 2: Several visits to the Hammersmith MRI scanner were carried out throughout the project. These visits were used to gather information about MRI scanners, understand the constraints of the specific MRI model, and conduct device testing. However, MRI scanners are a valuable and heavily booked resource, often with limited availability for extended periods. This created difficulties during certain stages of the project, particularly testing, as no scanner time was available for days or even weeks. A more effective approach would have been to book regular weekly sessions during quieter periods from the start of the project, as access to the scanner would have been necessary regardless of the final device design. Project Management lesson 3: The team consisted of eight members, each of whom contributed to a range of tasks throughout the project. Tasks were allocated broadly according to individual skills and availability. However, the team did not formally identify each member’s strengths and interests at the outset, which made this gradual allocation process more difficult and, at times, inefficient. In future, it would be advisable to assess individual strengths and preferences at the start of the project and assign more clearly defined roles, such as procurement lead or fabrication lead.

10.00

25.00

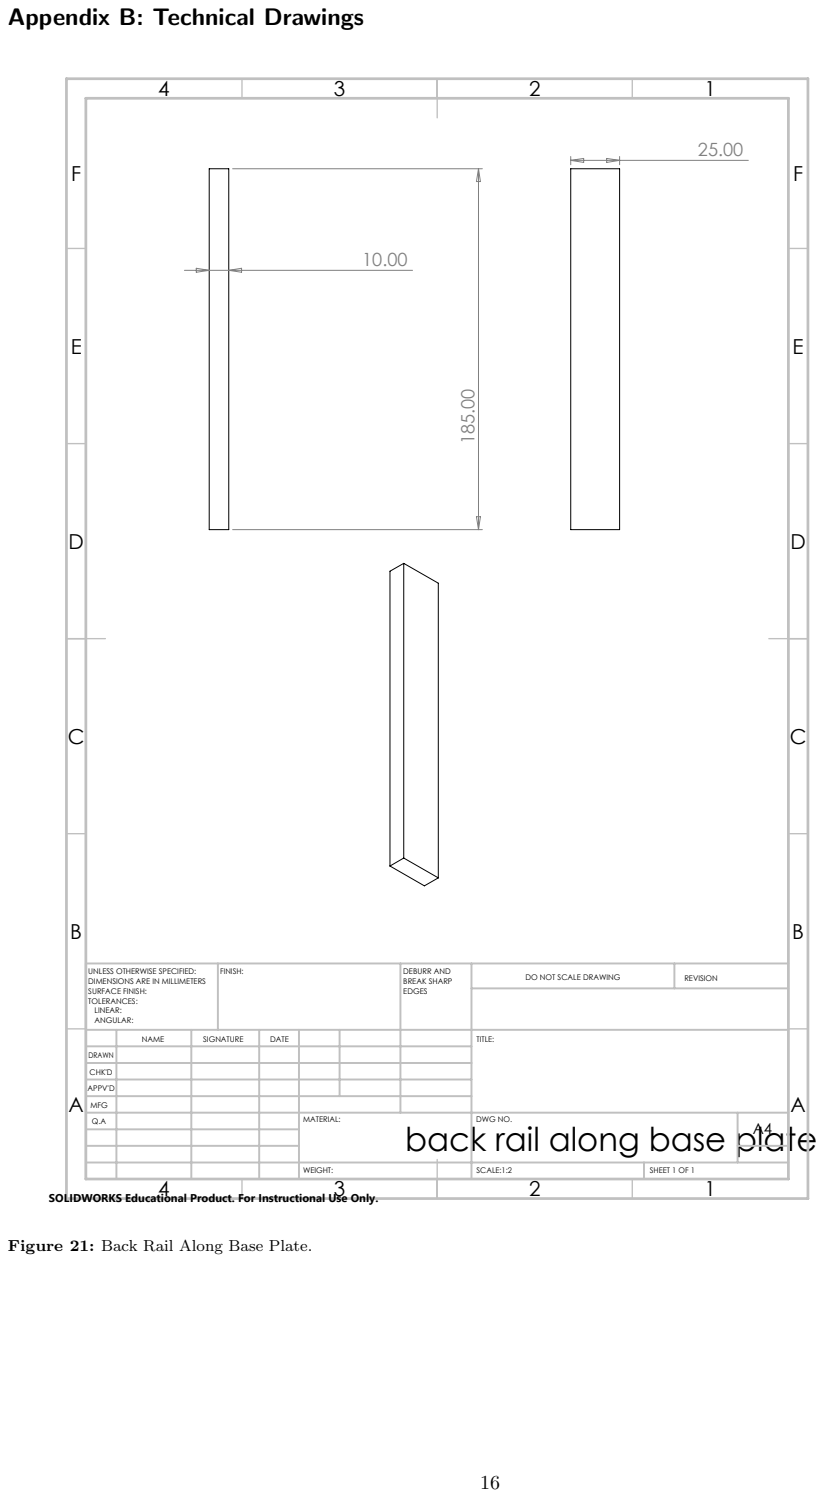
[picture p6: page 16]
FINISH:; DEBURR AND; BREAK SHARP EDGES; DO NOT SCALE DRAWING; REVISION; SCALE:1:2; SHEET 1 OF 1; WEIGHT:

Appendix B: Technical Drawings

UNLESS OTHERWISE SPECIFIED:
DIMENSIONS ARE IN MILLIMETERS
SURFACE FINISH:
TOLERANCES:
LINEAR:
ANGULAR:

NAME | SIGNATURE | DATE | | | TITLE:

DRAWN
CHK'D
APPV'D
MFG
Q.A | | | | MATERIAL: | DWG NO. | A4

back rail along base plate

SOLIDWORKS Educational Product. For Instructional Use Only.

Figure 21: Back Rail Along Base Plate.

E | | E
F | F

UNLESS OTHERWISE SPECIFIED:
DIMENSIONS ARE IN MILLIMETERS
SURFACE FINISH:
TOLERANCES:
LINEAR:
ANGULAR:

NAME | SIGNATURE | DATE | | | TITLE:

DRAWN
CHK'D
APPV'D
MFG
Q.A | | | | MATERIAL: | DWG NO. Base plate | A4

SOLIDWORKS Educational Product. For Instructional Use Only.

Figure 22: Base Plate.

48.50

48.50

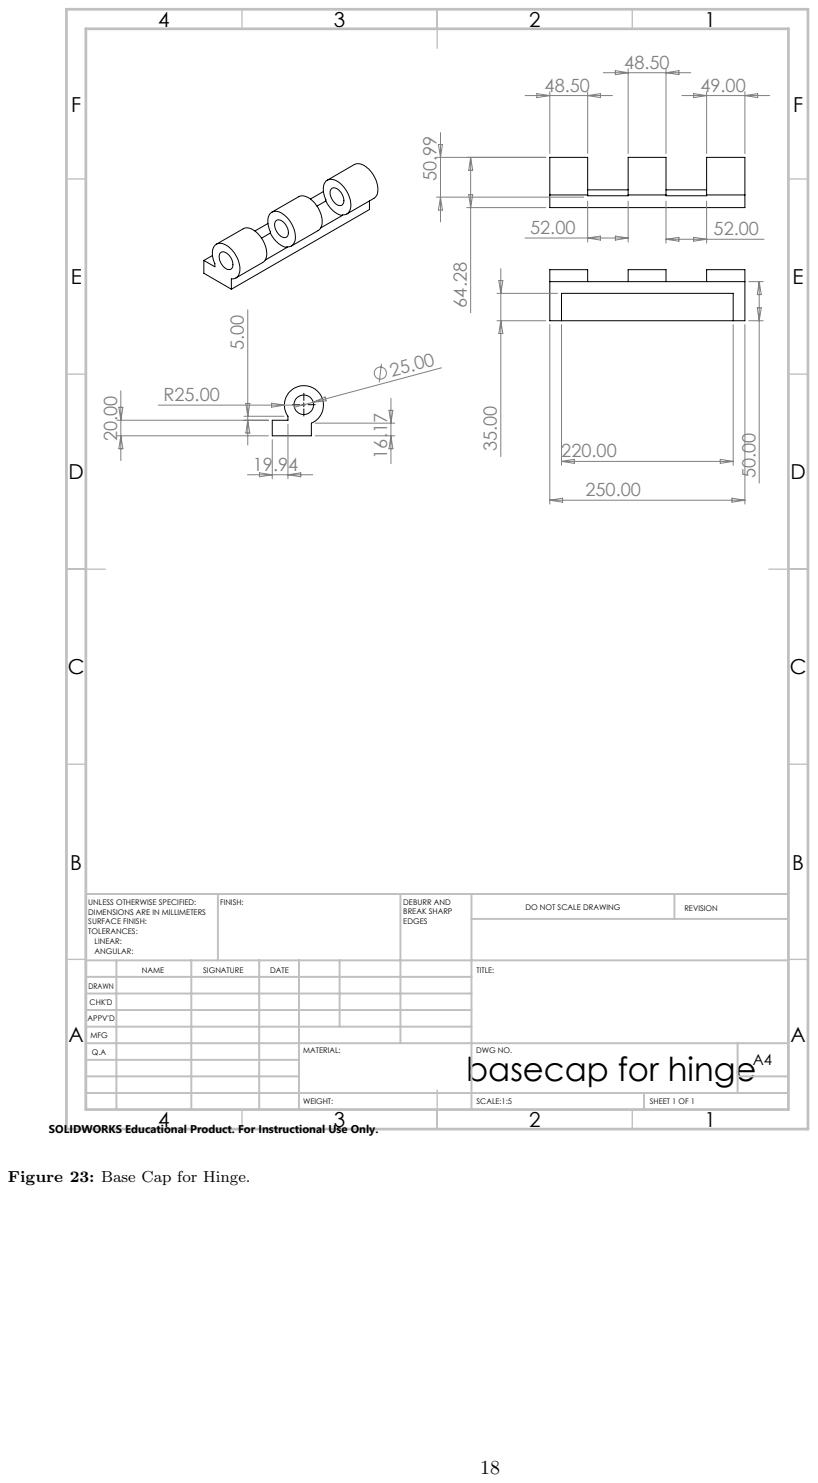
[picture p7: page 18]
FINISH:; DEBURR AND; BREAK SHARP EDGES; DO NOT SCALE DRAWING; REVISION; SCALE:1:5; SHEET 1 OF 1; WEIGHT:

UNLESS OTHERWISE SPECIFIED:
DIMENSIONS ARE IN MILLIMETERS
SURFACE FINISH:
TOLERANCES:
LINEAR:
ANGULAR:

NAME | SIGNATURE | DATE | | | TITLE:

DRAWN
CHK'D
APPV'D
MFG
Q.A | | | | MATERIAL: basecap for hinge | DWG NO. | A4

SOLIDWORKS Educational Product. For Instructional Use Only.

Figure 23: Base Cap for Hinge.

24.80

E | | E

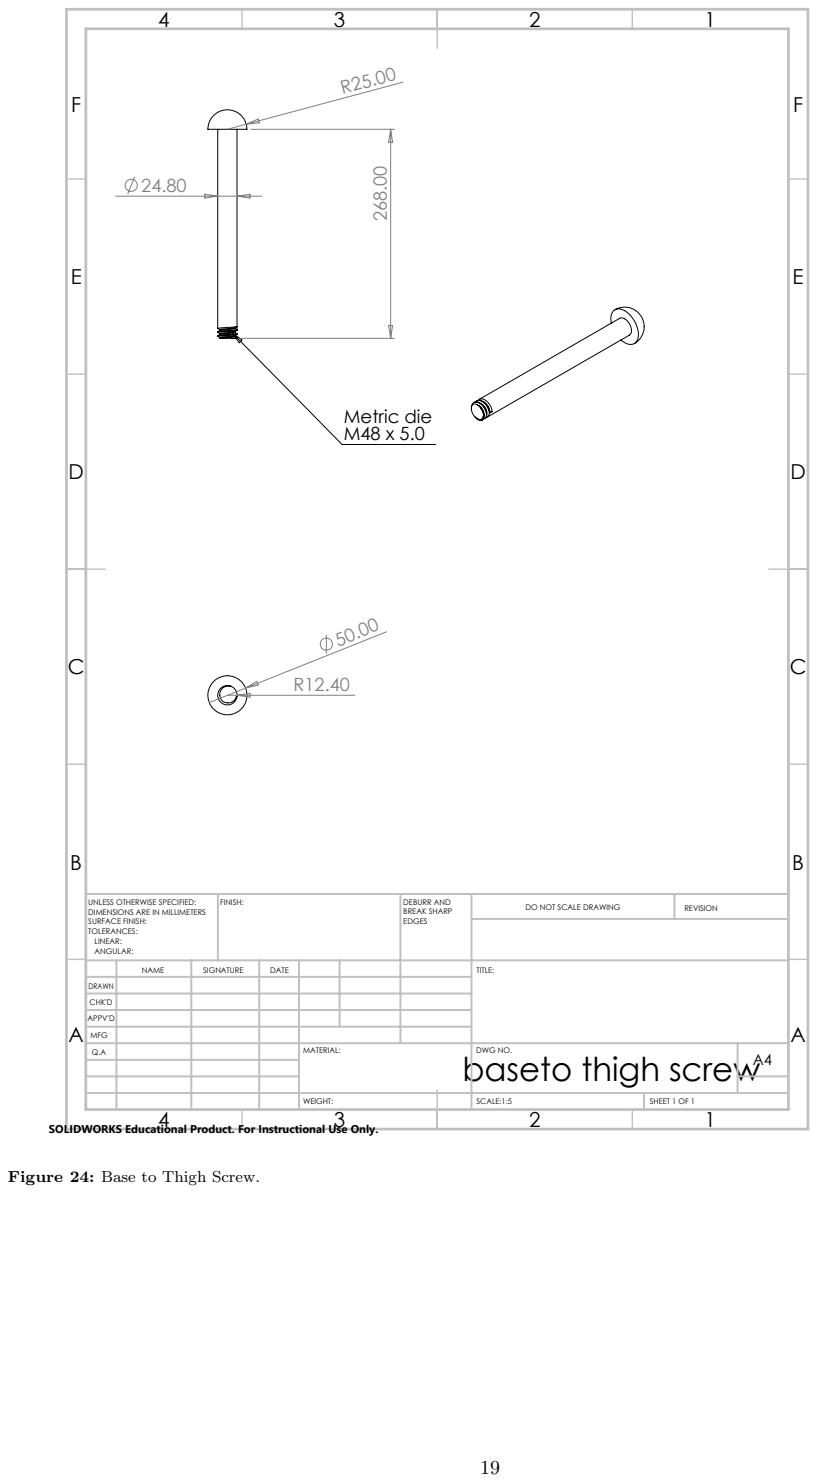
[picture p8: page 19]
Metric die M48 x 5.0; FINISH:; DEBURR AND; BREAK SHARP EDGES; DO NOT SCALE DRAWING; REVISION; SCALE:1:5; SHEET 1 OF 1; WEIGHT:

UNLESS OTHERWISE SPECIFIED:
DIMENSIONS ARE IN MILLIMETERS
SURFACE FINISH:
TOLERANCES:
LINEAR:
ANGULAR:

NAME | SIGNATURE | DATE | | | TITLE:

DRAWN
CHK'D
APPV'D
MFG
Q.A | | | | MATERIAL: baseto thigh screw | DWG NO. | A4

SOLIDWORKS Educational Product. For Instructional Use Only.

Figure 24: Base to Thigh Screw.

80.00 70.00
50.00

UNLESS OTHERWISE SPECIFIED:
DIMENSIONS ARE IN MILLIMETERS
SURFACE FINISH:
TOLERANCES:
LINEAR:
ANGULAR:

NAME | SIGNATURE | DATE | | | TITLE:

DRAWN
CHK'D
APPV'D
MFG
Q.A | | | | MATERIAL: | DWG NO. calf plate | A4

SOLIDWORKS Educational Product. For Instructional Use Only.

Figure 25: Calf Plate.

150.00

180.00

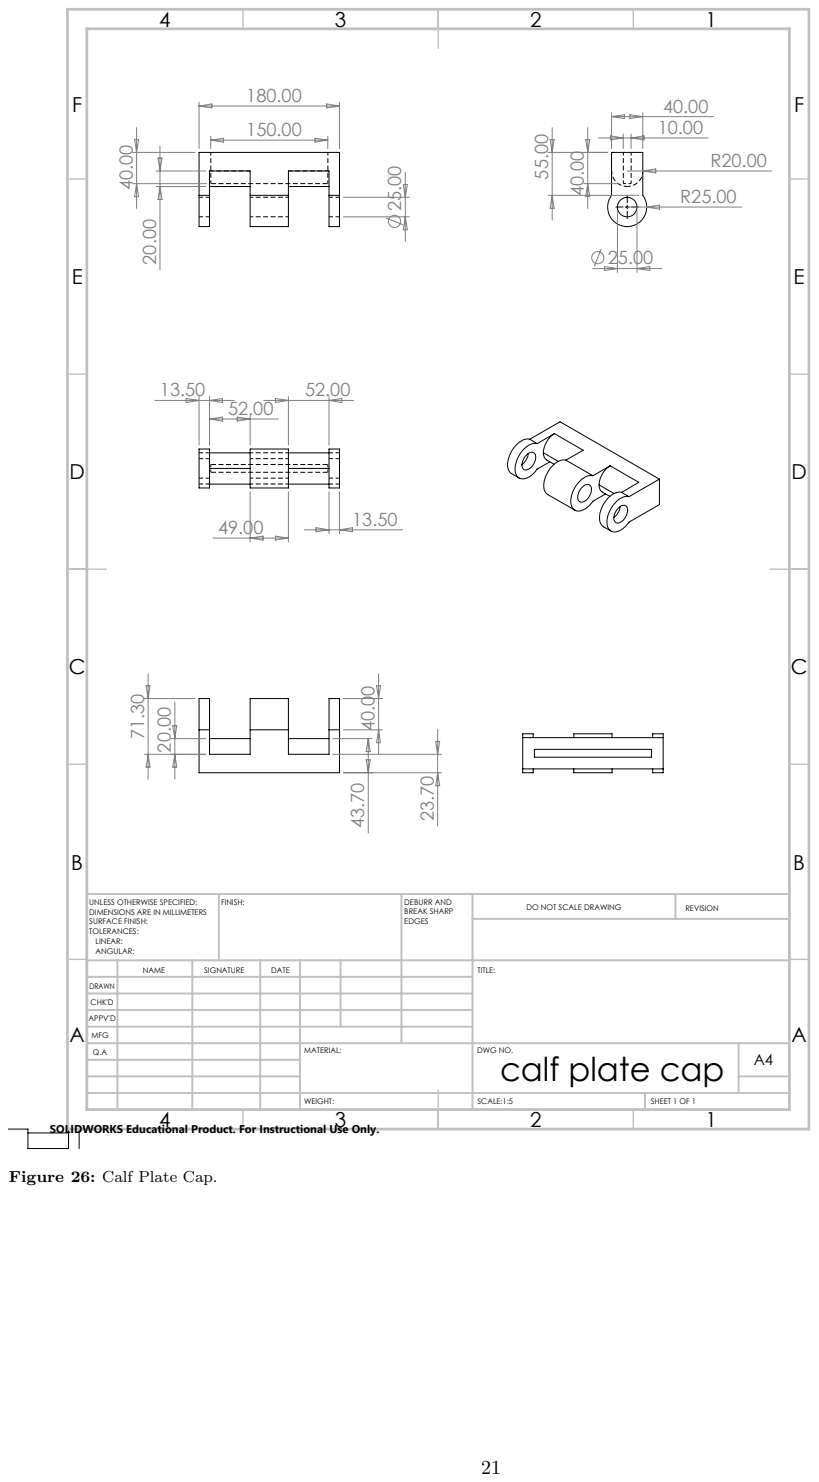
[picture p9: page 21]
FINISH:; DEBURR AND; BREAK SHARP EDGES; DO NOT SCALE DRAWING; REVISION; SCALE:1:5; SHEET 1 OF 1; WEIGHT:

UNLESS OTHERWISE SPECIFIED:
DIMENSIONS ARE IN MILLIMETERS
SURFACE FINISH:
TOLERANCES:
LINEAR:
ANGULAR:

NAME | SIGNATURE | DATE | | | TITLE:

DRAWN
CHK'D
APPV'D
MFG
Q.A | | | | MATERIAL: | DWG NO. calf plate cap | A4

SOLIDWORKS Educational Product. For Instructional Use Only.

Figure 26: Calf Plate Cap.

E | | E
F | F

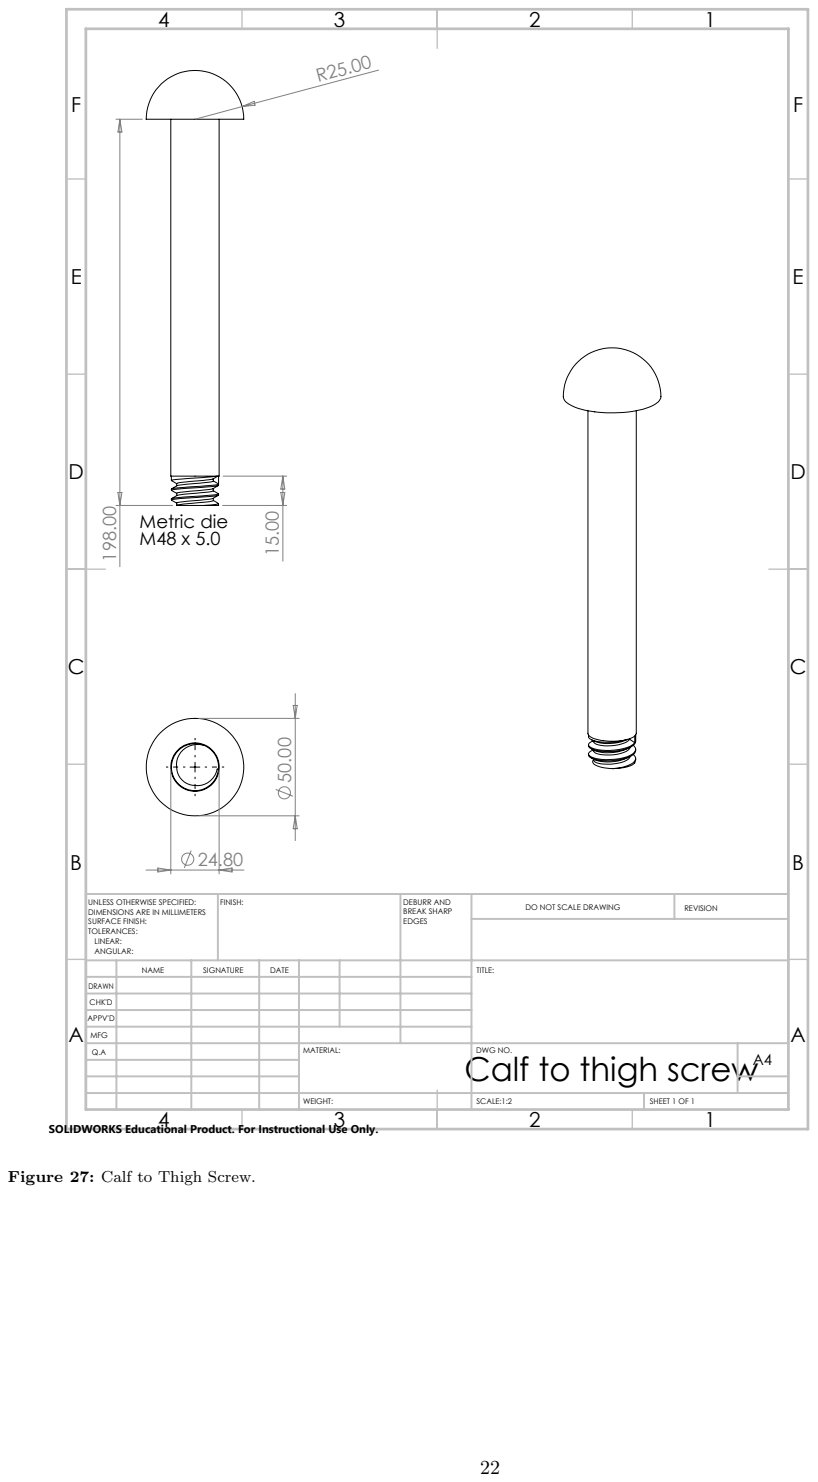
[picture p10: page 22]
Metric die M48 x 5.0; FINISH:; DEBURR AND; BREAK SHARP EDGES; DO NOT SCALE DRAWING; REVISION; SCALE:1:2; SHEET 1 OF 1; WEIGHT:

UNLESS OTHERWISE SPECIFIED:
DIMENSIONS ARE IN MILLIMETERS
SURFACE FINISH:
TOLERANCES:
LINEAR:
ANGULAR:

NAME | SIGNATURE | DATE | | | TITLE:

DRAWN
CHK'D
APPV'D
MFG
Q.A | | | | MATERIAL: Calf to thigh screw | DWG NO. | A4

SOLIDWORKS Educational Product. For Instructional Use Only.

Figure 27: Calf to Thigh Screw.

150.00
40.00 11.58

UNLESS OTHERWISE SPECIFIED:
DIMENSIONS ARE IN MILLIMETERS
SURFACE FINISH:
TOLERANCES:
LINEAR:
ANGULAR:

NAME | SIGNATURE | DATE | | | TITLE:

DRAWN
CHK'D
APPV'D
MFG
Q.A | | | | MATERIAL: | DWG NO. | A4

Cap for the end of the calf plate

SOLIDWORKS Educational Product. For Instructional Use Only.

Figure 28: Cap for the End of the Calf Plate.

E | E
F | F

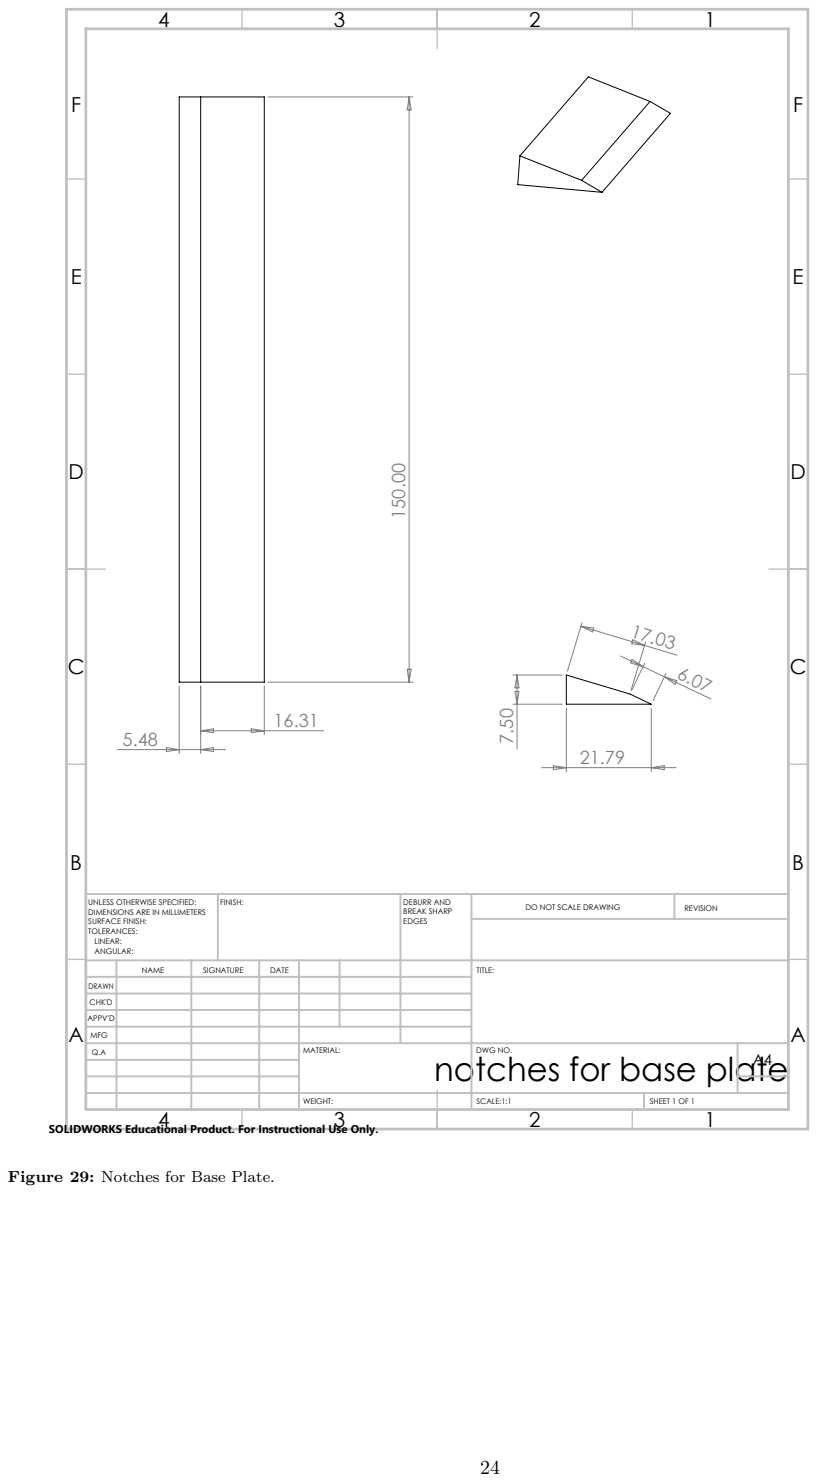
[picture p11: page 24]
FINISH:; DEBURR AND; BREAK SHARP EDGES; DO NOT SCALE DRAWING; REVISION; SCALE:1:1; SHEET 1 OF 1; WEIGHT:

UNLESS OTHERWISE SPECIFIED:
DIMENSIONS ARE IN MILLIMETERS
SURFACE FINISH:
TOLERANCES:
LINEAR:
ANGULAR:

NAME | SIGNATURE | DATE | | | TITLE:

DRAWN
CHK'D
APPV'D
MFG
Q.A | | | | MATERIAL: notches for base plate | DWG NO. | A4

SOLIDWORKS Educational Product. For Instructional Use Only.

Figure 29: Notches for Base Plate.

E | | E
F | F

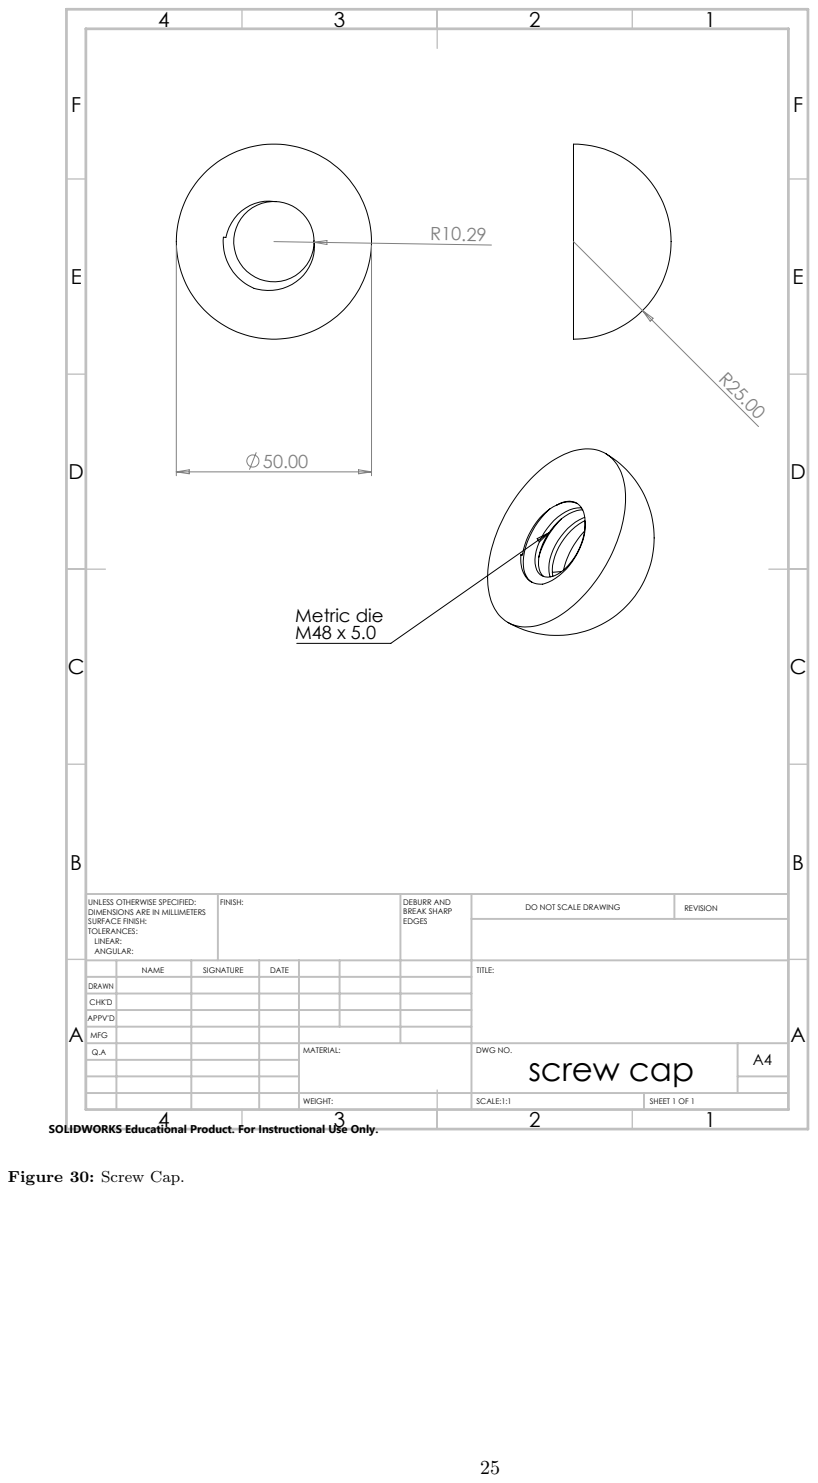
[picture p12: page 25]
Metric die M48 x 5.0; FINISH:; DEBURR AND; BREAK SHARP EDGES; DO NOT SCALE DRAWING; REVISION; SCALE:1:1; SHEET 1 OF 1; WEIGHT:

UNLESS OTHERWISE SPECIFIED:
DIMENSIONS ARE IN MILLIMETERS
SURFACE FINISH:
TOLERANCES:
LINEAR:
ANGULAR:

NAME | SIGNATURE | DATE | | | TITLE:

DRAWN
CHK'D
APPV'D
MFG
Q.A | | | | MATERIAL: | DWG NO. screw cap | A4

SOLIDWORKS Educational Product. For Instructional Use Only.

Figure 30: Screw Cap.

10.00

E | E

UNLESS OTHERWISE SPECIFIED:
DIMENSIONS ARE IN MILLIMETERS
SURFACE FINISH:
TOLERANCES:
LINEAR:
ANGULAR:

NAME | SIGNATURE | DATE | | | TITLE:

DRAWN
CHK'D
APPV'D
MFG
Q.A | | | | MATERIAL: | DWG NO. Thigh plate | A4

SOLIDWORKS Educational Product. For Instructional Use Only.

Figure 31: Thigh Plate.

50.00 | 50.00
50.00 | 40.00 40.00

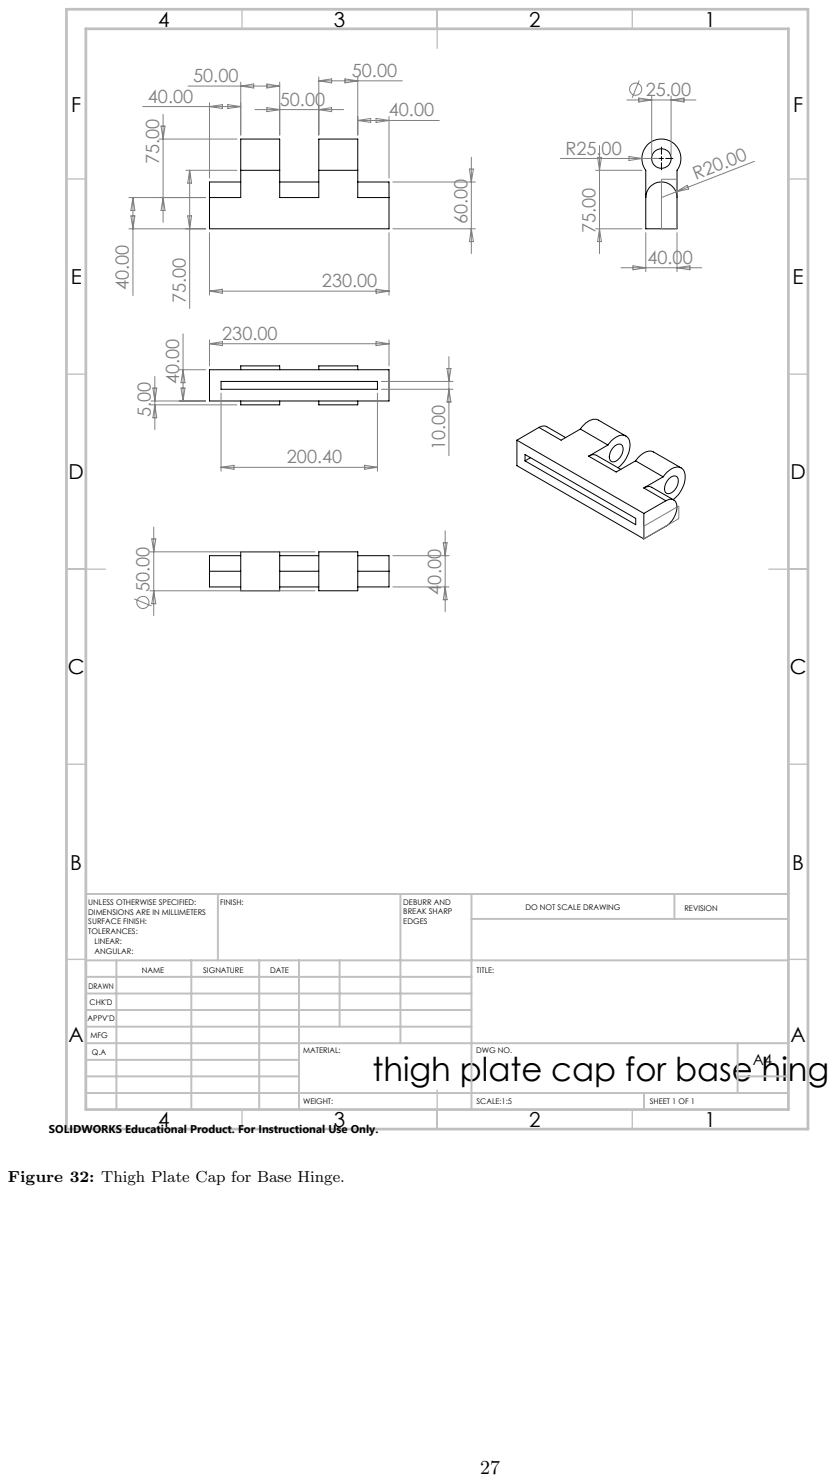
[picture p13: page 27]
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

UNLESS OTHERWISE SPECIFIED:
DIMENSIONS ARE IN MILLIMETERS
SURFACE FINISH:
TOLERANCES:
LINEAR:
ANGULAR:

NAME | SIGNATURE | DATE | | | TITLE:

DRAWN
CHK'D
APPV'D
MFG
Q.A | | | | MATERIAL: | DWG NO. | A4

thigh plate cap for base hinge

SOLIDWORKS Educational Product. For Instructional Use Only.

Figure 32: Thigh Plate Cap for Base Hinge.

15.00

53.00

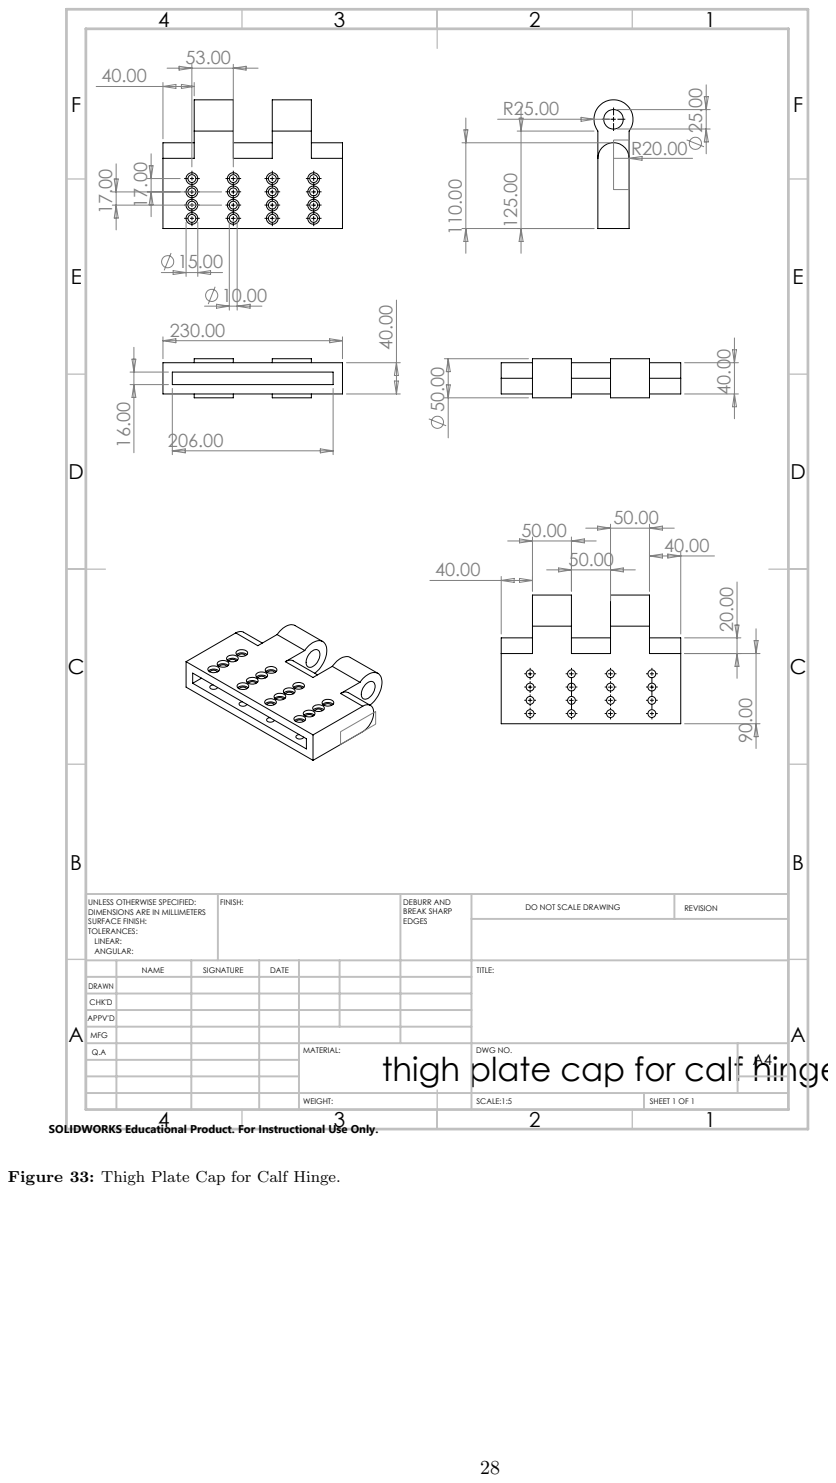
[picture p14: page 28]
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

UNLESS OTHERWISE SPECIFIED:
DIMENSIONS ARE IN MILLIMETERS
SURFACE FINISH:
TOLERANCES:
LINEAR:
ANGULAR:

NAME | SIGNATURE | DATE | | | TITLE:

DRAWN
CHK'D
APPV'D
MFG
Q.A | | | | MATERIAL: | DWG NO. | A4

thigh plate cap for calf hinge

SOLIDWORKS Educational Product. For Instructional Use Only.

Figure 33: Thigh Plate Cap for Calf Hinge.

167.00

25.00

UNLESS OTHERWISE SPECIFIED:
DIMENSIONS ARE IN MILLIMETERS
SURFACE FINISH:
TOLERANCES:
LINEAR:
ANGULAR:

NAME | SIGNATURE | DATE | | | TITLE:

DRAWN
CHK'D
APPV'D
MFG
Q.A | | | | MATERIAL: | DWG NO. Backplate | A4

Figure 34: Backplate of Loading Component.

162.00
50.00

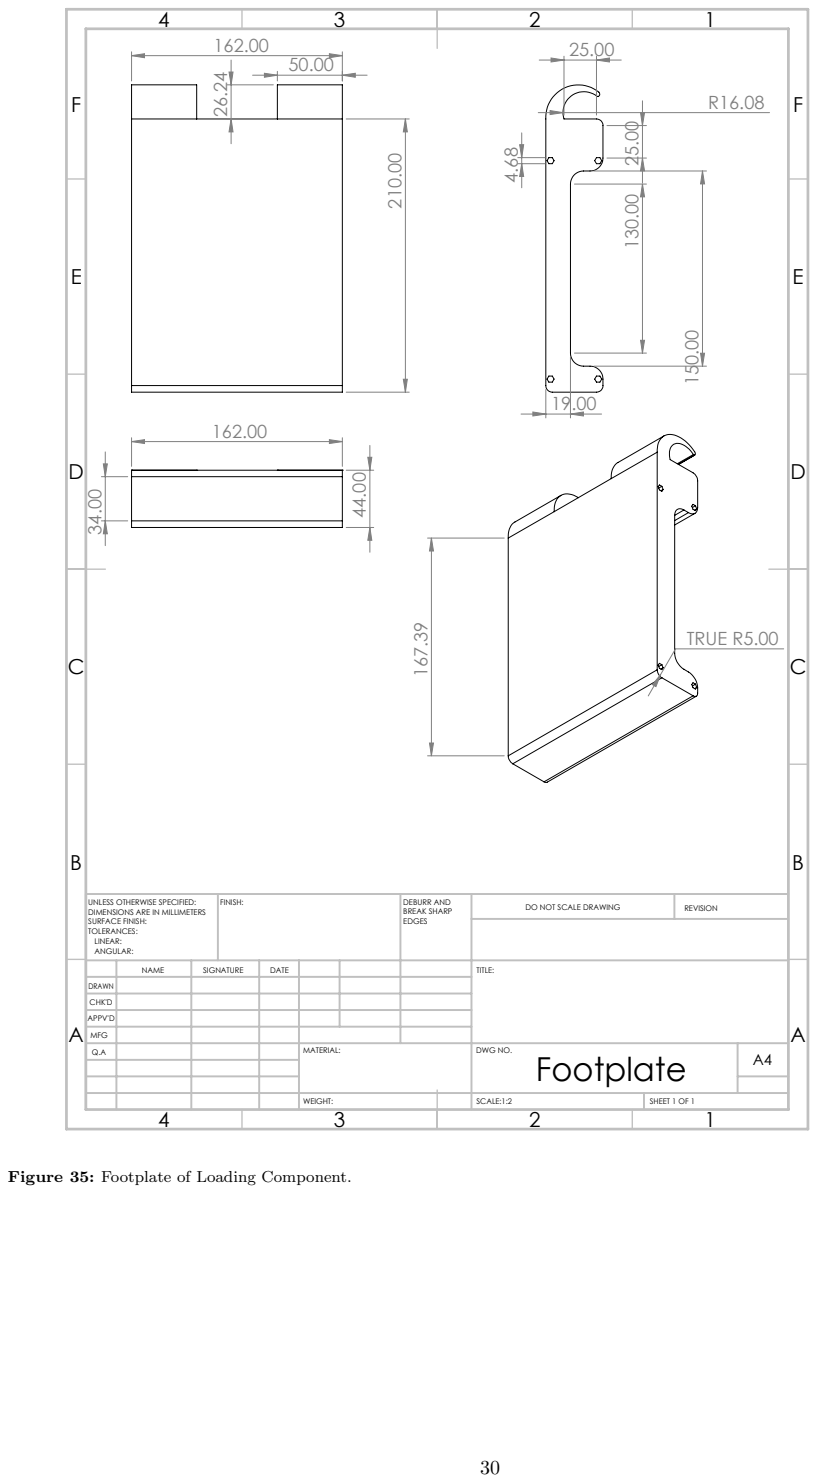
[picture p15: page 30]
TRUE R5.00; FINISH:; DEBURR AND; BREAK SHARP EDGES; DO NOT SCALE DRAWING; REVISION; SCALE:1:2; SHEET 1 OF 1; WEIGHT:

UNLESS OTHERWISE SPECIFIED:
DIMENSIONS ARE IN MILLIMETERS
SURFACE FINISH:
TOLERANCES:
LINEAR:
ANGULAR:

NAME | SIGNATURE | DATE | | | TITLE:

DRAWN
CHK'D
APPV'D
MFG
Q.A | | | | MATERIAL: | DWG NO. Footplate | A4

Figure 35: Footplate of Loading Component.

E | E
F | F

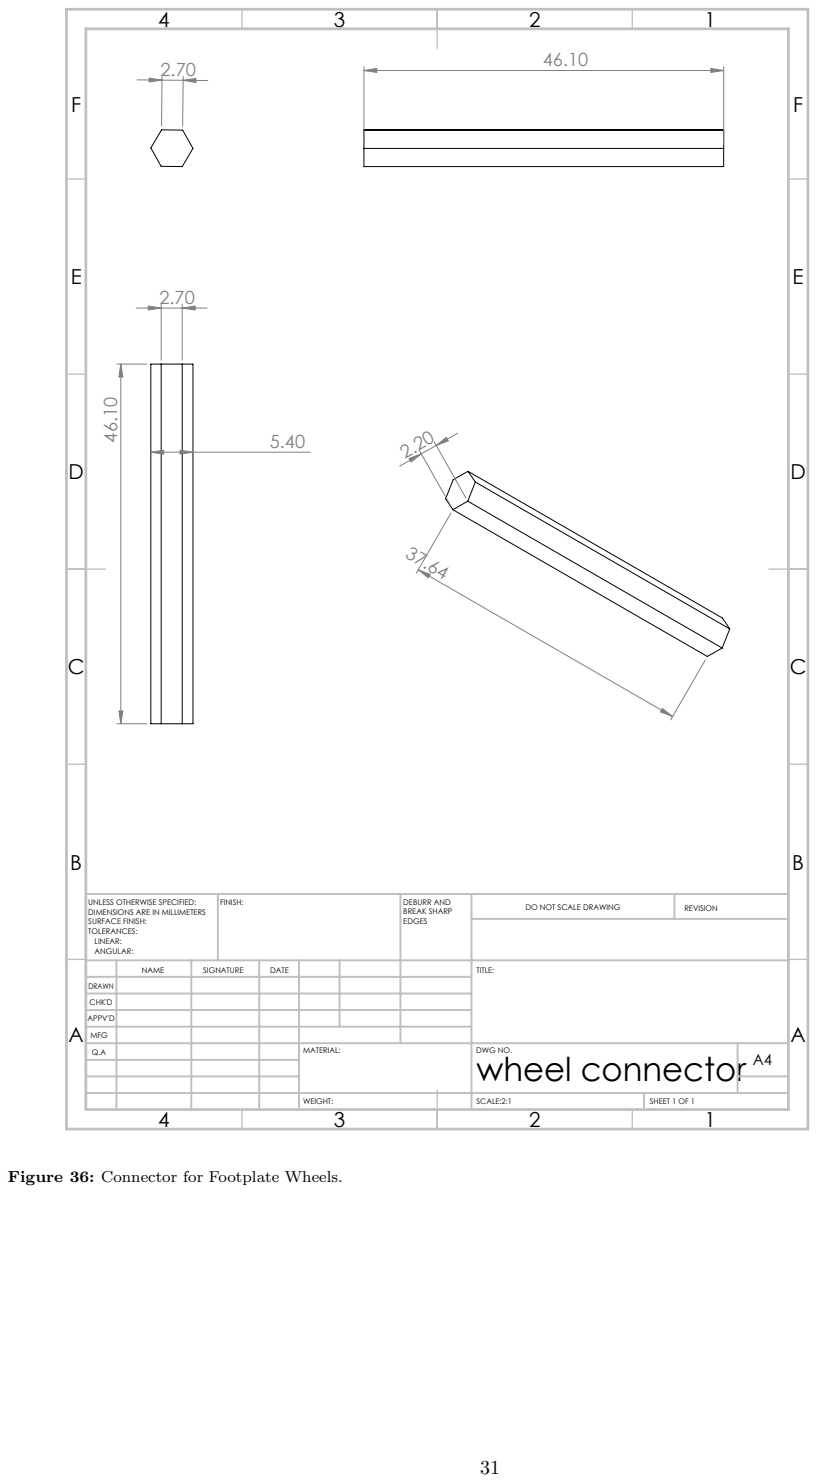
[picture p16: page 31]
FINISH:; DEBURR AND; BREAK SHARP EDGES; DO NOT SCALE DRAWING; REVISION; SCALE:2:1; SHEET 1 OF 1; WEIGHT:

UNLESS OTHERWISE SPECIFIED:
DIMENSIONS ARE IN MILLIMETERS
SURFACE FINISH:
TOLERANCES:
LINEAR:
ANGULAR:

NAME | SIGNATURE | DATE | | | TITLE:

DRAWN
CHK'D
APPV'D
MFG
Q.A | | | | MATERIAL: | DWG NO. wheel connector | A4

Figure 36: Connector for Footplate Wheels.

4.85

E | E

UNLESS OTHERWISE SPECIFIED:
DIMENSIONS ARE IN MILLIMETERS
SURFACE FINISH:
TOLERANCES:
LINEAR:
ANGULAR:

NAME | SIGNATURE | DATE | | | TITLE:

DRAWN
CHK'D
APPV'D
MFG
Q.A | | | | MATERIAL: | DWG NO. wheel stopper | A4

Figure 37: Wheel Stopper Nut for Footplate.

17.00

## R9.00 R9.87 R10.73

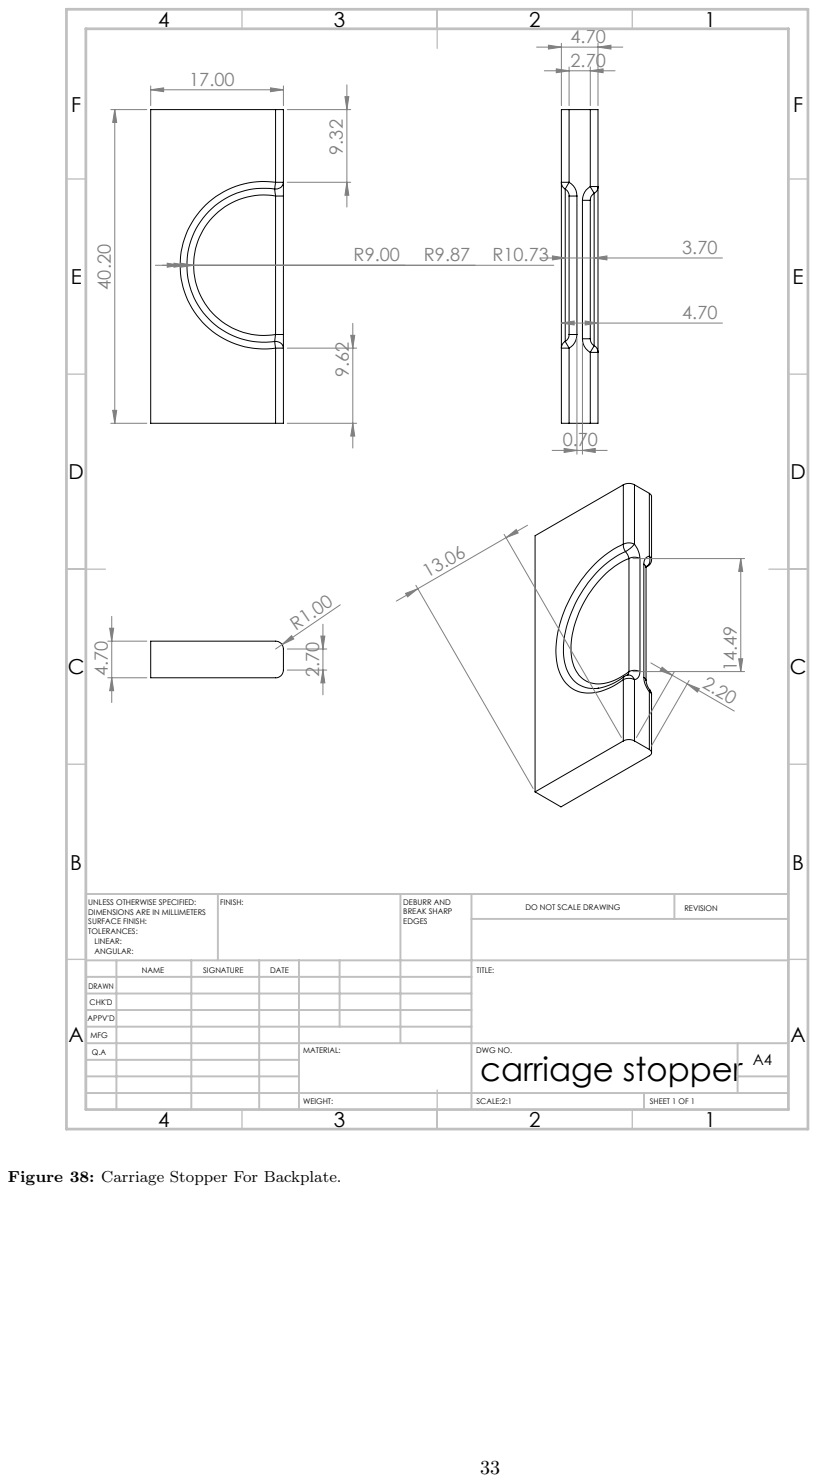
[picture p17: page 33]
FINISH:; DEBURR AND; BREAK SHARP EDGES; DO NOT SCALE DRAWING; REVISION; SCALE:2:1; SHEET 1 OF 1; WEIGHT:

UNLESS OTHERWISE SPECIFIED:
DIMENSIONS ARE IN MILLIMETERS
SURFACE FINISH:
TOLERANCES:
LINEAR:
ANGULAR:

NAME | SIGNATURE | DATE | | | TITLE:

DRAWN
CHK'D
APPV'D
MFG
Q.A | | | | MATERIAL: | DWG NO. carriage stopper | A4

Figure 38: Carriage Stopper For Backplate.

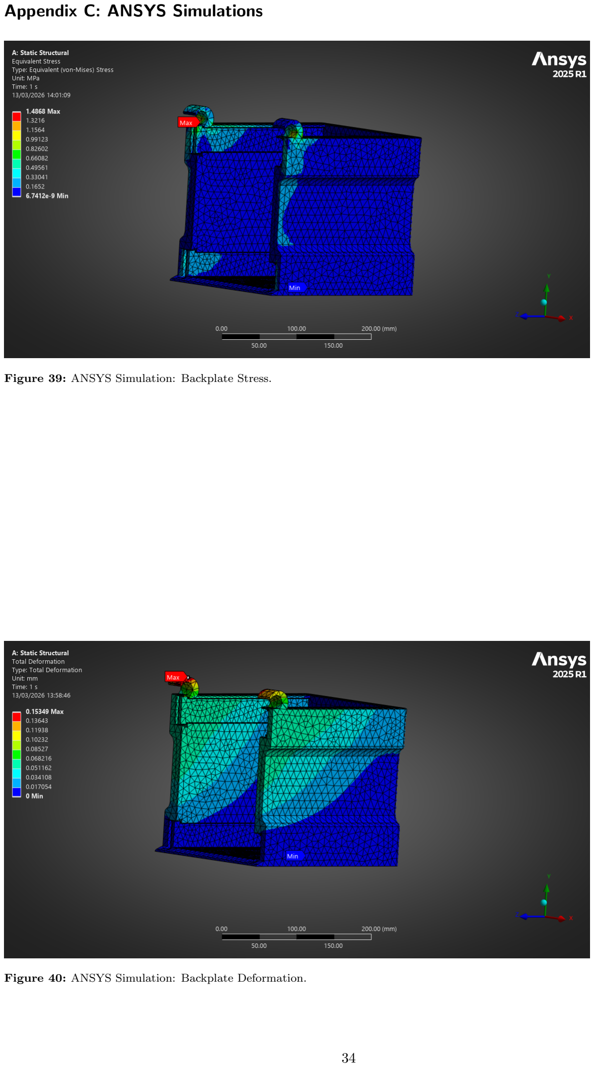
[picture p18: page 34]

Appendix C: ANSYS Simulations

Figure 39: ANSYS Simulation: Backplate Stress.

Figure 40: ANSYS Simulation: Backplate Deformation.

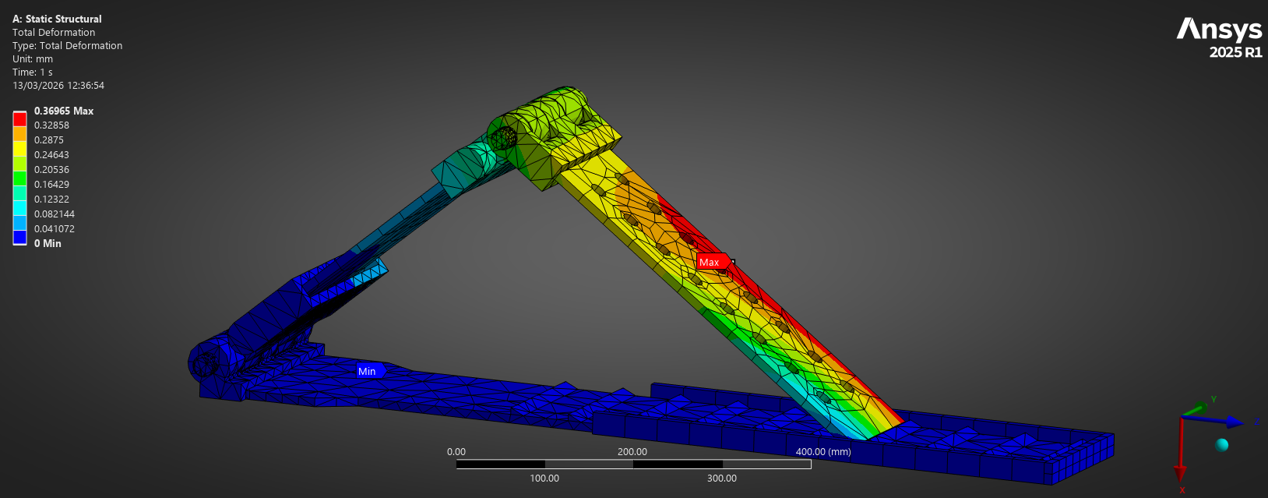
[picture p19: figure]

Figure 41: ANSYS Simulation: Final Design Deformation.

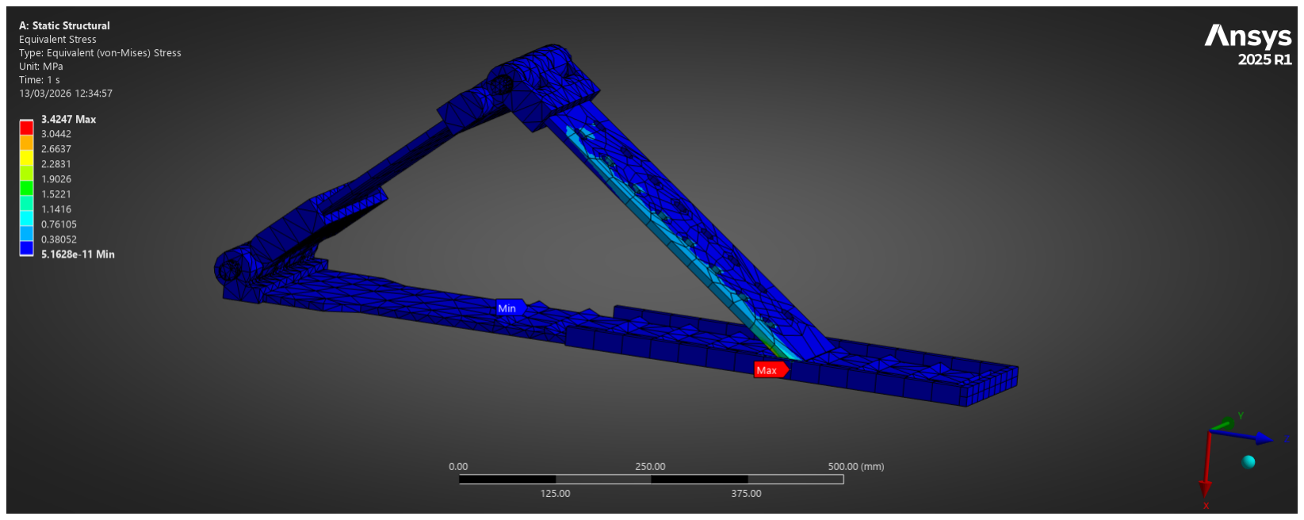
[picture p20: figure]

Figure 42: ANSYS Simulation: Final Design Stress.

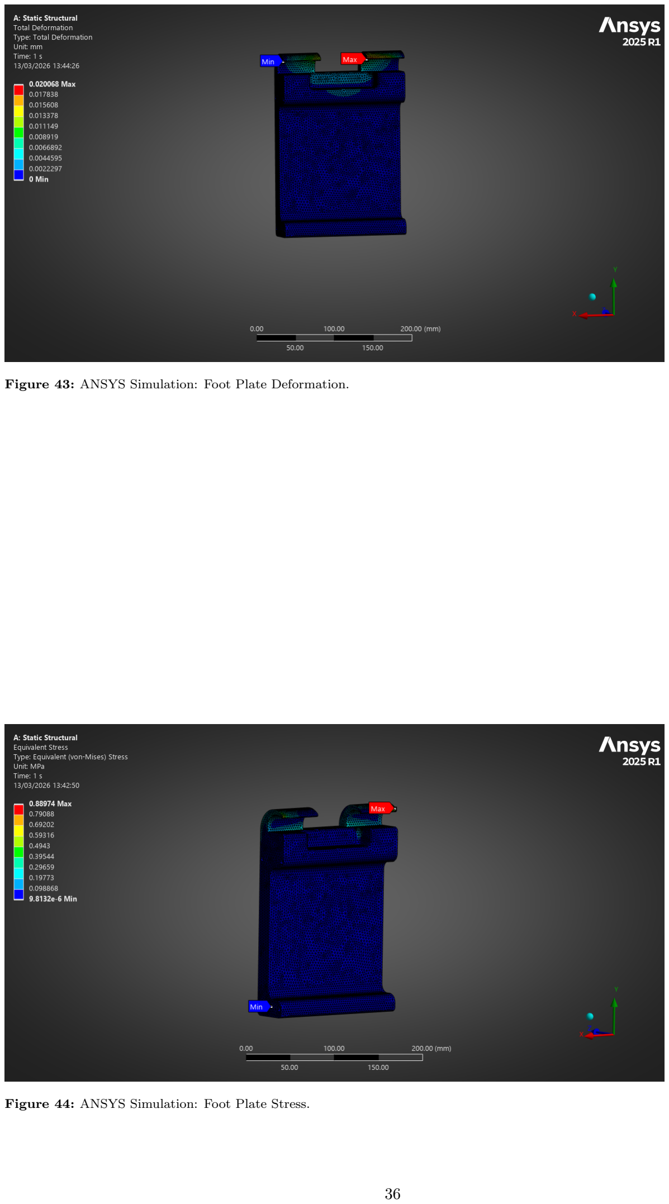
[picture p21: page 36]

Figure 43: ANSYS Simulation: Foot Plate Deformation.

Figure 44: ANSYS Simulation: Foot Plate Stress.

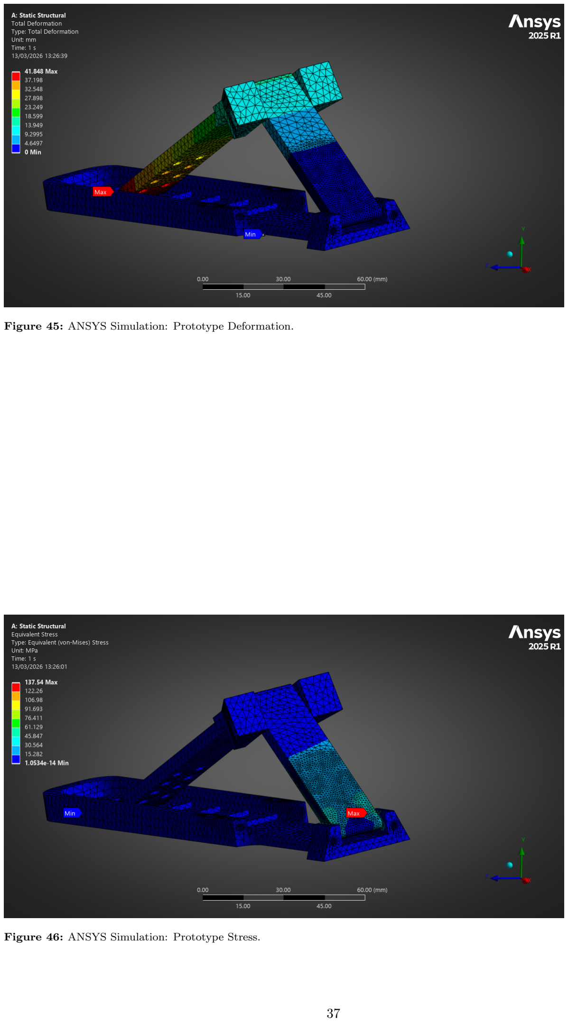
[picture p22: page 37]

Figure 45: ANSYS Simulation: Prototype Deformation.

Figure 46: ANSYS Simulation: Prototype Stress.

## Healthy Volunteer Feedback Form 1. Comfort Rate 1 (very poor) to 10 (excellent) - Overall comfort while positioned: 1–10 - Comfort at maximum load: 1–10 - Comfort at highest knee angle: 1–10 Did you experience any pain?

☐ No | ☐ Mild | ☐ Moderate | ☐ Severe

If yes, where? ___________________ 2. Stability & Security - Did you feel physically stable during loading? 1–10 - Did you feel supported at each angle? 1–10 - Did you feel at risk of slipping or shifting? 1–10 (10 = completely secure) Comments on stability: ___________________ 3. Ease of Use - Ease of getting into position: 1–10 - Ease of adjusting angles: 1–10 - Ease of applying load: 1–10 - Clarity of instructions: 1–10 Did anything feel confusing? ___________________ 4. Safety - Did you feel safe throughout the test? 1–10 - Did the device feel mechanically robust? 1–10 - Did you trust it under load? 1–10 At any point did you feel unsafe?

☐ No

☐ Yes → Explain: ___________________ 5. Mechanical Feel - Smoothness of movement between angles: 1–10 - Smoothness of load application: 1–10 Describe anything that felt off: _____________________________________ 6. Tolerability Over Time - Could you comfortably hold position for 5–10 minutes? 1–10 - Would you tolerate a full MRI scan in this device? 1–10

Appendix D: Healthy Volunteer Feedback Form

## 7. Overall Impression - Overall device rating: 1–10 - Would you be comfortable being scanned in this device? ☐ Yes

☐ No

## ☐ Unsure 8. Open Feedback - What felt best about the device? ___________________________________________

## - What felt worst? __________________________________________________________

## - One thing we must improve before clinical use: _____________________________

## I confirm that:

- I have voluntarily participated in testing the MRI-Safe Dynamic Knee Loading Device.
- I understand that my feedback will be used to inform device improvements.
- I consent to anonymised data from this form being included in academic reports.
- I understand that no identifying personal information will be published.

## Participant Name (print): ______________________ Signature: ______________________ Date: ______________________

clear;
clc;
close all;

% User Settings
filename = 'Gauge_testing.csv';

% Set original lengths used for strain calculations.
L0_unfolded_cm = 30; % stated band length
L0_folded_cm = L0_unfolded_cm/2; % folded assumed half effective free length

alpha = 0.05; % significance level

% Import data
opts = detectImportOptions(filename); T = readtable(filename, opts);

disp('Column names detected:') disp(T.Properties.VariableNames')

% Extract unfolded data
xU = T{:, 'Displacement_cm_'}; FU = [T{:,'Force1_N_'}, ... T{:,'Force2_N_'}, ...
T{:,'Force3_N_'}, ...
T{:,'Force4_N_'}, ...
T{:,'Force5_N_'}];

% Extract folded data
xF = T{:, 'Displacement_cm__1'}; FF = [T{:,'Force1_N__1'}, ... T{:,'Force2_N__1'}, ...
T{:,'Force3_N__1'}, ...
T{:,'Force4_N__1'}, ...
T{:,'Force5_N__1'}];

% Remove rows with missing displacement values validU = ~isnan(xU);
validF = ~isnan(xF);

xU = xU(validU);
FU = FU(validU,:);

xF = xF(validF);
FF = FF(validF,:);

nTrialsU = size(FU,2);
nTrialsF = size(FF,2);

% Basic descriptive statistics meanU = mean(FU, 2, 'omitnan');
stdU = std(FU, 0, 2, 'omitnan');
semU = stdU ./ sqrt(nTrialsU);
tcritU = tinv(1 - alpha/2, nTrialsU - 1); ciU = tcritU .* semU;

Appendix E: Resistance Band Data Analysis Code meanF = mean(FF, 2, 'omitnan');
stdF = std(FF, 0, 2, 'omitnan');
semF = stdF ./ sqrt(nTrialsF);
tcritF = tinv(1 - alpha/2, nTrialsF - 1); ciF = tcritF .* semF;

cvU = 100 * stdU ./ meanU;
cvF = 100 * stdF ./ meanF;

% Display summary tables
summaryUnfolded = table(xU, meanU, stdU, semU, ciU, cvU, 'VariableNames', {'Displacement_cm','MeanForce_N','SD_N','SEM_N','CI95_halfwidth_N','CV_percent'});

summaryFolded = table(xF, meanF, stdF, semF, ciF, cvF,'VariableNames', {'Displacement_cm','MeanForce_N','SD_N','SEM_N','CI95_halfwidth_N','CV_percent'});

disp(' ')
disp('Unfolded summary:')
disp(summaryUnfolded)

disp(' ')
disp('Folded summary:')
disp(summaryFolded)

% Plot raw repeats
figure('Name','Raw force-displacement data','Color','w'); tiledlayout(1,2)

nexttile
plot(xU, FU, 'o-', 'LineWidth', 1.2) xlabel('Displacement (cm)') ylabel('Force (N)')
title('Unfolded: all repeats') grid on

nexttile
plot(xF, FF, 'o-', 'LineWidth', 1.2) xlabel('Displacement (cm)') ylabel('Force (N)')
title('Folded: all repeats')
grid on
exportgraphics(gcf, 'raw_force_displacement.png', 'Resolution', 300);

% Plot mean ± 95% CI
figure('Name','Mean force with 95% CI','Color','w');
hold on
errorbar(xU, meanU, ciU, 'o-', 'LineWidth', 1.5, 'CapSize', 8) errorbar(xF, meanF, ciF, 's-', 'LineWidth', 1.5, 'CapSize', 8) xlabel('Displacement (cm)')
ylabel('Force (N)')
title('Mean force-displacement response with 95% CI') legend('Unfolded','Folded','Location','northwest')
grid on
hold off
exportgraphics(gcf, 'mean_force_ci.png', 'Resolution', 300);

% Linear and quadratic model fits using mean response mdlU_lin = fitlm(xU, meanU, 'linear'); mdlU_quad = fitlm(xU, meanU, 'quadratic');

mdlF_lin = fitlm(xF, meanF, 'linear'); mdlF_quad = fitlm(xF, meanF, 'quadratic');

disp(' ')
disp('Unfolded linear model:') disp(mdlU_lin)

disp(' ')
disp('Unfolded quadratic model:') disp(mdlU_quad)

disp(' ')
disp('Folded linear model:') disp(mdlF_lin)

disp(' ')
disp('Folded quadratic model:')
disp(mdlF_quad)

% Compare linear vs quadratic fits using adjusted R^2 and AIC modelCompare = table( ...
["Unfolded"; "Unfolded"; "Folded"; "Folded"], ...
["Linear"; "Quadratic"; "Linear"; "Quadratic"], ...
[mdlU_lin.Rsquared.Adjusted; mdlU_quad.Rsquared.Adjusted; mdlF_lin.Rsquared.Adjusted; mdlF_quad.Rsquared.Adjusted], ...
[mdlU_lin.ModelCriterion.AIC; mdlU_quad.ModelCriterion.AIC; mdlF_lin.ModelCriterion.AIC; mdlF_quad.ModelCriterion.AIC], ...
'VariableNames', {'Condition','Model','AdjR2','AIC'});

disp(' ')
disp('Model comparison:')
disp(modelCompare)

% Overlay model fits
xU_fit = linspace(min(xU), max(xU), 200)'; xF_fit = linspace(min(xF), max(xF), 200)';

yU_lin = predict(mdlU_lin, xU_fit); yU_quad = predict(mdlU_quad, xU_fit);

yF_lin = predict(mdlF_lin, xF_fit); yF_quad = predict(mdlF_quad, xF_fit);

figure('Name','Model fits','Color','w'); tiledlayout(1,2)

nexttile
plot(xU, meanU, 'ko', 'MarkerFaceColor','auto'); hold on plot(xU_fit, yU_lin, '-', 'LineWidth', 1.5) plot(xU_fit, yU_quad, '--', 'LineWidth', 1.5) xlabel('Displacement (cm)')
ylabel('Force (N)')
title('Unfolded fit')
legend('Mean data','Linear','Quadratic','Location','northwest')

grid on

nexttile
plot(xF, meanF, 'ko', 'MarkerFaceColor','auto'); hold on plot(xF_fit, yF_lin, '-', 'LineWidth', 1.5) plot(xF_fit, yF_quad, '--', 'LineWidth', 1.5) xlabel('Displacement (cm)')
ylabel('Force (N)')
title('Folded fit')
legend('Mean data','Linear','Quadratic','Location','northwest') grid on
exportgraphics(gcf, 'model_fits.png', 'Resolution', 300);

% Stiffness estimates
% Global stiffness from linear fit slope kU_global_N_per_cm = mdlU_lin.Coefficients.Estimate(2); kF_global_N_per_cm = mdlF_lin.Coefficients.Estimate(2);

kU_global_N_per_m = 100 * kU_global_N_per_cm; kF_global_N_per_m = 100 * kF_global_N_per_cm;

% Local incremental stiffness from mean curve kU_local = diff(meanU) ./ diff(xU); kF_local = diff(meanF) ./ diff(xF);

xU_mid = (xU(1:end-1) + xU(2:end))/2; xF_mid = (xF(1:end-1) + xF(2:end))/2;

disp(' ')
fprintf('Global unfolded stiffness: %.3f N/cm (%.1f N/m)\n', kU_global_N_per_cm, kU_global_N_per_m);
fprintf('Global folded stiffness: %.3f N/cm (%.1f N/m)\n', kF_global_N_per_cm, kF_global_N_per_m);

figure('Name','Local stiffness','Color','w');
hold on
plot(xU_mid, kU_local, 'o-', 'LineWidth', 1.4) plot(xF_mid, kF_local, 's-', 'LineWidth', 1.4) xlabel('Displacement midpoint (cm)')
ylabel('Local stiffness (N/cm)')
title('Incremental stiffness from mean force-displacement curve') legend('Unfolded','Folded','Location','northwest')
grid on
hold off
exportgraphics(gcf, 'local_stiffness.png', 'Resolution', 300);

% Convert to engineering strain
strainU = xU / L0_unfolded_cm;
strainF = xF / L0_folded_cm;

% Plot force vs engineering strain
figure('Name','Force vs engineering strain','Color','w');
hold on
errorbar(strainU, meanU, ciU, 'o-', 'LineWidth', 1.5, 'CapSize', 8) errorbar(strainF, meanF, ciF, 's-', 'LineWidth', 1.5, 'CapSize', 8) xlabel('Strain, \epsilon = \DeltaL / L_0')
ylabel('Force (N)')

title('Force-Strain comparison') legend('Unfolded','Folded','Location','northwest')
grid on
hold off
exportgraphics(gcf, 'force_vs_strain.png', 'Resolution', 300);

% Build long-format table for inferential statistics
% Unfolded
[dispGridU, trialGridU] = ndgrid(xU, 1:nTrialsU); longU = table( ...
FU(:), ...
dispGridU(:), ...
repmat(strainU, nTrialsU, 1), ...
repmat(categorical("Unfolded"), numel(FU), 1), ... categorical(trialGridU(:)), ...
'VariableNames', {'Force_N','Displacement_cm','Strain','Condition','Trial'});

% Folded
[dispGridF, trialGridF] = ndgrid(xF, 1:nTrialsF);
longF = table( ...
FF(:), ...
dispGridF(:), ...
repmat(strainF, nTrialsF, 1), ...
repmat(categorical("Folded"), numel(FF), 1), ... categorical(trialGridF(:)), ...
'VariableNames', {'Force_N','Displacement_cm','Strain','Condition','Trial'});

longData = [longU; longF];

% Mixed-effects model
% This tests whether force depends on strain, condition, and their interaction, % while accounting for repeated trials.
lme = fitlme(longData, 'Force_N ~ Condition*Strain + (1|Trial)');

disp(' ')
disp('Linear mixed-effects model:')
disp(lme)

anovaLME = anova(lme);
disp(' ')
disp('LME ANOVA:')
disp(anovaLME)

% Pointwise folded vs unfolded comparison at matched strain levels
% Since xF is half xU, strain may align if L0 assumptions are correct. commonStrain = intersect(strainU, strainF);

if ~isempty(commonStrain)
pVals = nan(numel(commonStrain),1); hVals = nan(numel(commonStrain),1); meanDiff = nan(numel(commonStrain),1);

for i = 1:numel(commonStrain)
s = commonStrain(i);

idxU = find(abs(strainU - s) < 1e-12, 1); idxF = find(abs(strainF - s) < 1e-12, 1);

dataU = FU(idxU, :);
dataF = FF(idxF, :);

% Paired t-test across repeats
[h, p] = ttest(dataF, dataU, 'Alpha', alpha);

hVals(i) = h;
pVals(i) = p;
meanDiff(i) = mean(dataF - dataU); end

% Benjamini-Hochberg FDR correction [p_sorted, sortIdx] = sort(pVals); m = numel(pVals);
thresh = (1:m)'/m * alpha;
below = p_sorted <= thresh; sigFDR = false(size(pVals));
if any(below)
k = find(below, 1, 'last'); sigFDR(sortIdx(1:k)) = true;
end

pointwiseStats = table(commonStrain, meanDiff, pVals, sigFDR, ... 'VariableNames',
{'Strain','MeanForceDifference_FoldedMinusUnfolded_N','pValue','Significant_FDR'});

disp(' ')
disp('Pointwise strain-matched folded vs unfolded tests:')
disp(pointwiseStats)
else
warning('No common strain values found. Check L0 assumptions for folded and unfolded conditions.');
end

% Residual diagnostics for preferred models
% Choose lower AIC model for each condition
if mdlU_quad.ModelCriterion.AIC < mdlU_lin.ModelCriterion.AIC bestU = mdlU_quad;
bestU_name = 'Quadratic';
else
bestU = mdlU_lin;
bestU_name = 'Linear';
end

if mdlF_quad.ModelCriterion.AIC < mdlF_lin.ModelCriterion.AIC bestF = mdlF_quad;
bestF_name = 'Quadratic';
else
bestF = mdlF_lin;
bestF_name = 'Linear';
end

resU = bestU.Residuals.Raw;
resF = bestF.Residuals.Raw;

% Lilliefors normality tests on residuals

[hU_norm, pU_norm] = lillietest(resU); [hF_norm, pF_norm] = lillietest(resF);

disp(' ')
fprintf('Best unfolded model: %s, residual normality p = %.4f\n', bestU_name, pU_norm); fprintf('Best folded model: %s, residual normality p = %.4f\n', bestF_name, pF_norm);

figure('Name','Residual diagnostics','Color','w');
tiledlayout(2,2)

nexttile
qqplot(resU)
title(['Unfolded residuals Q-Q: ' bestU_name])

nexttile
histogram(resU)
xlabel('Residual')
ylabel('Count')
title('Unfolded residual histogram') grid on

nexttile
qqplot(resF)
title(['Folded residuals Q-Q: ' bestF_name])

nexttile
histogram(resF)
xlabel('Residual')
ylabel('Count')
title('Folded residual histogram')
grid on
exportgraphics(gcf, 'residual_diagnostics.png', 'Resolution', 300);

% Force target estimates for device
targetForces = [50, 100, 150, 200]'; % N

% Using linear models
targetDispU_cm = (targetForces - mdlU_lin.Coefficients.Estimate(1)) / mdlU_lin.Coefficients.Estimate(2);
targetDispF_cm = (targetForces - mdlF_lin.Coefficients.Estimate(1)) / mdlF_lin.Coefficients.Estimate(2);

targetTable = table(targetForces, targetDispU_cm, targetDispF_cm, ... 'VariableNames',
{'TargetForce_N','EstimatedDisp_Unfolded_cm','EstimatedDisp_Folded_cm'});

disp(' ')
disp('Estimated displacements for target loads, from linear fits:') disp(targetTable)

% Save outputs
writetable(summaryUnfolded, 'summary_unfolded.csv');
writetable(summaryFolded, | 'summary_folded.csv');
writetable(modelCompare, | 'model_comparison.csv');

if exist('pointwiseStats','var')

writetable(pointwiseStats, 'pointwise_strain_tests.csv'); end

writetable(targetTable, 'target_force_estimates.csv');

disp(' ')
disp('Analysis complete.')

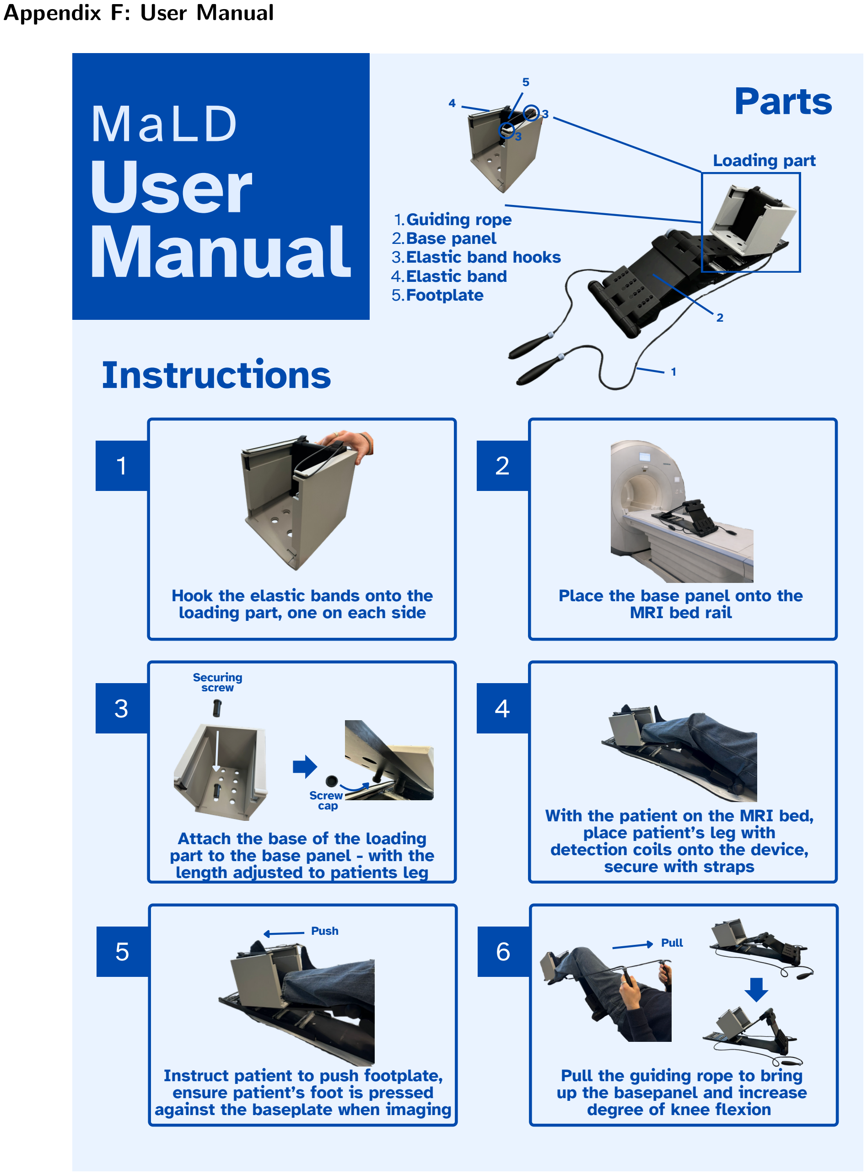
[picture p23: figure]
Appendix F: User Manual; 1.Guiding rope 2.Base panel 3.Elastic band hooks 4.Elastic band 5.Footplate; User Manual; MaLD; Parts; Hook the elastic bands onto the loading part, one on each side; Place the base panel onto the MRI bed rail; Attach the base of the loading part to the base panel - with the length adjusted to patients leg; With the patient on the MRI bed, place patient’s leg with detection coils onto the device, secure with straps; Pull the guiding rope to bring up the basepanel and increase degree of knee flexion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

Figure 47: User Manual

Appendix G: Bill of Materials

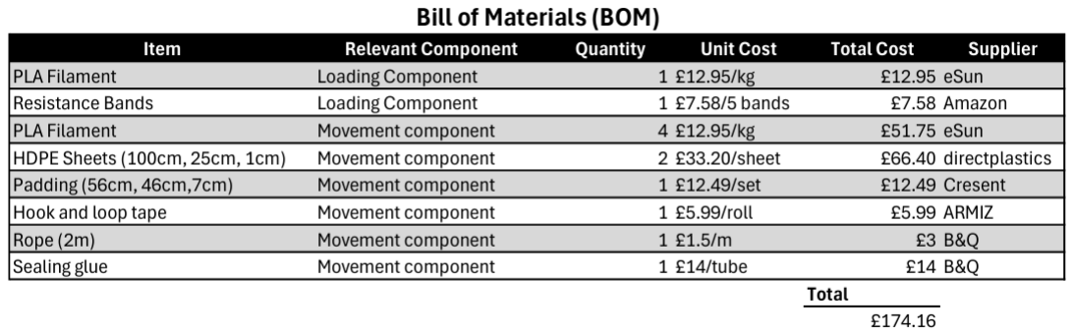
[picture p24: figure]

Figure 48: Bill of Materials for Device Construction (BOM)

## References

[1] Cross M, Smith E, Hoy DG, Nolte S, Ackerman I, Fransen M, et al. The global burden of hip and knee osteoarthritis: estimates from the Global Burden of Disease 2010 study. Annals of the Rheumatic Diseases. 2014;73(7):1323-30.
[2] Long H, Liu Q, Yin H, Wang K, Diao N, Zhang Y, et al. Prevalence trends of site-specific osteoarthritis from 1990 to 2019: findings from the Global Burden of Disease Study 2019. Arthritis & Rheumatology. 2022;74(7):1172-83.
[3] Felson DT. Osteoarthritis as a disease of mechanics. Osteoarthritis and Cartilage. 2013;21(1):10-5.
[4] Jerban S, Chang EY, Du J. Magnetic resonance imaging (MRI) studies of knee joint under mechanical loading: review. Magnetic Resonance Imaging. 2020;65:27-36.
[5] Chien A, Weaver JS, Kinne E, Omar I. Magnetic resonance imaging of the knee. Polish Journal of Radiology. 2020;85:e509-31.
[6] Shin CS, Souza RB, Kumar D, Link TM, Wyman BT, Majumdar S. In vivo tibiofemoral cartilage-tocartilage contact area of females with medial osteoarthritis under acute loading using MRI. Journal of Magnetic Resonance Imaging. 2011;34(6):1405-13.
[7] Patel R, Eltgroth M, Souza RB, Zhang CA, Majumdar S, Link TM, et al. Loaded versus unloaded magnetic resonance imaging of the knee: effect on meniscus extrusion in healthy volunteers and patients with osteoarthritis. Eur J Radiol Open. 2016;3:100-7.
[8] Englund M, Guermazi A, Roemer FW, Aliabadi P, Yang M, Lewis CE, et al. Meniscal tear in knees without surgery and the development of radiographic osteoarthritis among middle-aged and elderly persons: The Multicenter Osteoarthritis Study. Arthritis & Rheumatism. 2009;60(3):831-9.
[9] Bruno F, Barile A, Arrigoni F, Laporta A, Russo A, Carotti M, et al. Weight-bearing MRI of the knee: a review of advantages and limits. Acta Biomedica. 2018;89(Suppl 1):78-88.
[10] Kijowski R, Blankenbaker DG, Davis KW, Shinki K, Kaplan LD, De Smet AA. Comparison of 1.5-T and 3.0-T MR imaging for evaluating the articular cartilage of the knee joint. Radiology. 2009;250(3):839-48.
[11] Draper CE, Besier TF, Santos JM, Jennings F, Fredericson M, Gold GE, et al. Using real-time MRI to quantify altered joint kinematics in subjects with patellofemoral pain and to evaluate the effects of a patellar brace or sleeve on joint motion. Journal of Orthopaedic Research. 2009;27(5):571-7.
[12] Shellock FG, Woods TO, Crues JV. MR labeling information for implants and devices: explanation of terminology. Radiology. 2009;253(1):26-30.
[13] Brisson NM, Kr¨amer M, Krahl LAN, Schill A, Duda GN, Reichenbach JR. A novel multipurpose device for guided knee motion and loading during dynamic magnetic resonance imaging. Zeitschrift f¨ur Medizinische Physik. 2022;32(4):500-13.
[14] Medicines and Healthcare products Regulatory Agency. Safety Guidelines for Magnetic Resonance Imaging Equipment in Clinical Use. MHRA; 2021. Available from: https://assets.publishing.service.gov.uk/government/uploads/system/uploads/attachment_data/file/958486/MRI_guidance_2021-4-03c.pdf.
[15] Rowe PJ, Myles CM, Walker C, Nutton R. Knee joint kinematics in gait and other functional activities measured using flexible electrogoniometry: how much knee motion is sufficient for normal daily life? Gait & Posture. 2000;12(2):143-55.
[16] Kutzner I, Heinlein B, Graichen F, Bender A, Rohlmann A, Halder A, et al. Loading of the knee joint during activities of daily living measured in vivo in five subjects. Journal of Biomechanics. 2010;43(11):2164-73.
[17] Souza RB, Stehling C, Wyman BT, Hellio Le Graverand MP, Li X, Link TM, et al. The effects of acute loading on T1ρ and T2 relaxation times of tibiofemoral articular cartilage. Osteoarthritis and Cartilage. 2010;18(12):1557-63.
[18] Stehling C, Souza RB, Hellio Le Graverand MP, Wyman BT, Li X, Majumdar S, et al. Loading of the knee during 3.0T MRI is associated with significantly increased medial meniscus extrusion in mild and moderate osteoarthritis. European Journal of Radiology. 2012;81(8):1839-45.
[19] Lange T, Knowles BR, Herbst M, Izadpanah K, Zaitsev M. Comparative T2 and T1ρ mapping of patellofemoral cartilage under in situ mechanical loading with prospective motion correction. Journal of Magnetic Resonance Imaging. 2017;46(2):452-60.
[20] Said O, Schock J, Kr¨amer N, Th¨uring J, Hitpass L, Schad P, et al. An MRI-compatible varus–valgus loading device for whole-knee joint functionality assessment based on compartmental compression: a proofof-concept study. Magnetic Resonance Materials in Physics, Biology and Medicine. 2020;33(6):839-54.

[21] Craddock W, Smithers T, Harris C, du Moulin W, Molnar R. Magnetic resonance imaging of the posterior cruciate ligament in flexion. Knee. 2018 Jun;25(3):507-12.
[22] Jogi SP, Thaha R, Rajan S, Mahajan V, Venugopal VK, Mehndiratta A, et al. Device for assessing knee joint dynamics during magnetic resonance imaging. Journal of Magnetic Resonance Imaging. 2022;55(3):895-907.
[23] Buur EC. The Design of an MRI-Compatible Knee Loading Device: Evaluating Soft Tissue Responses to Indicate Early Osteoarthritis [MSc Thesis]. Delft, Netherlands: Delft University of Technology; 2024.
[24] Moraczewski K, Stepczynska M, Malinowski R, Rytlewski P. Improving the impact strength and heat resistance of 3D printed models: structure, property, and processing correlationships during fused deposition modeling (FDM) of poly(lactic acid). ACS Omega. 2018;3(12):17062-74.
[25] Santos IA, Carvalho LH, Canedo EL, Alves TS, Barbosa R. Impact of different mineral reinforcements on HDPE composites: effects of melt flow index and particle size on physical and mechanical properties. Polymers. 2024;16(14):2012.
[26] Huang SH, Liu P, Mokasdar A, Hou L. Additive manufacturing and its societal impact: a literature review. The International Journal of Advanced Manufacturing Technology. 2013;67(5–8):1191-203.
[27] Li X, Mahadas NA, Zhang M, DePodesta J, Stefik M, Tang C. Sustainable high-density polyethylene via chemical recycling: from modification to polymerization methods. Polymer. 2024;295:126698.
[28] ANSYS, Inc . ANSYS Mechanical; 2024. Release 2024 R1. Available from: https://www.ansys.com.
[29] Schneider CA, Rasband WS, Eliceiri KW. NIH Image to ImageJ: 25 years of image analysis. Nature Methods. 2012;9(7):671-5.
[30] Patterson RM, Stegink Jansen CW, Hogan HA, Nassif MD. Material properties of Thera-Band tubing. Physical Therapy. 2001;81(8):1437-45.
[31] Lautrup B. Physics of Continuous Matter: Exotic and Everyday Phenomena in the Macroscopic World. 2nd ed. CRC Press; 2011.
[32] de Lima FF, Camillo CA, Reis EAPD, Job AE, Silva BSA, Topalovic M, et al. Mechanical properties, safety and resistance values of Lemgruber® elastic tubing. Brazilian Journal of Physical Therapy. 2018;22(6):523-32.
[33] Chac´on JM, Caminero MA, Garc´ıa-Plaza E, N´u˜nez PJ. Additive manufacturing of PLA structures us- ´ ing fused deposition modelling: effect of process parameters on mechanical properties and their optimal selection. Materials & Design. 2017;124:143-57.
[34] Scott ME, Beynnon BD, Borah AS, Ramsdell JC, Krug MI, Gardner-Morse MG, et al. Quantitative MRI-measured composition changes despite small mechanical measures in tibiofemoral cartilage of healthy adults under applied load. Journal of Biomechanics. 2025;190:112864.
[35] Lange T, Maclaren J, Herbst M, Lovell-Smith C, Izadpanah K, Zaitsev M. Knee cartilage MRI with in situ mechanical loading using prospective motion correction. Magnetic Resonance in Medicine. 2014;71(2):516-23.
[36] Teng HL, Calixto NE, Link TM, Majumdar S, Souza RB. Knee flexion moment and impulse during walking are associated with patellofemoral joint articular cartilage T1ρ and T2 relaxation time. Osteoarthritis and Cartilage. 2015;23(Suppl 2):A75-6.
[37] Hunter DJ, Bierma-Zeinstra SMA. Osteoarthritis. The Lancet. 2019;393(10182):1745-59.
[38] Yang B, Tan UX, McMillan AB, Gullapalli R, Desai JP. Design and control of a 1-DOF MRI-compatible pneumatically actuated robot with long transmission lines. IEEE/ASME Transactions on Mechatronics. 2011;16(6):1040-8.
[39] McRobbie DW, Moore EA, Graves MJ, Prince MR. MRI from Picture to Proton. 3rd ed. Cambridge University Press; 2017.
[40] ASTM International. ASTM F2052-21: Standard Test Method for Measurement of Magnetically Induced Displacement Force on Medical Devices in the Magnetic Resonance Environment. West Conshohocken, PA: ASTM International; 2021. Available from: https://www.astm.org/f2052-21.html.
[41] ASTM International. ASTM F2119-07(2013): Standard Test Method for Evaluation of MR Image Artifacts from Passive Implants. West Conshohocken, PA: ASTM International; 2013. Available from: https: //www.astm.org/f2119-07r13.html.
[42] Barile A, Conti L, Lanni G, Calvisi V, Masciocchi C. Evaluation of medial meniscus tears and meniscal stability: weight-bearing MRI vs arthroscopy. European Journal of Radiology. 2013;82(4):633-9.
[43] Neu CP. Functional Imaging in OA: Role of Imaging in the Evaluation of Tissue Biomechanics. Osteoarthritis and Cartilage. 2014;22(10):1349-59.

[44] Jovicich J, Czanner S, Greve D, Haley E, van der Kouwe A, Gollub R, et al. Reliability in multi-site structural MRI studies: effects of gradient non-linearity correction on phantom and human data. NeuroImage. 2006;30(2):436-43.
[45] Doran SJ, Charles-Edwards L, Reinsberg SA, Leach MO. A complete distortion correction for MR images:
I. Gradient warp correction. Physics in Medicine and Biology. 2005;50(7):1343-61.
[46] Souza RB, Baum T, Wu S, Feeley BT, Kadel N, Li X, et al. Effects of unloading on knee articular cartilage T1ρ and T2 magnetic resonance imaging relaxation times: a case series. Journal of Orthopaedic & Sports Physical Therapy. 2012;42(6):511-20.
[47] Mayr MF, Meine H, Lange T, Yilmaz T, Taghizadeh E, Schmal H, et al. In vivo kinematics of knee joint cartilage and meniscus contact areas under load application: a biomechanical MRI study. Archives of Orthopaedic and Trauma Surgery. 2026;146(1):77.

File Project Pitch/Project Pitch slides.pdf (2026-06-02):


Knee MRI Movement and Loading Device

Presented by ScanOperators
Jacob Beeson, Leonardo Grimaldi, Ben Jones, Amy Li, Sheena Ling, Belle Mok, Tayeb Tadlaoui, Hannah Wei

# MaLD

Supervisor: Dr. Pete Lally

# How low can you go :)


# Knee Issues in the UK

Population of; > 50 years old; Population of > 50 years old

Reported knee pain

Did not report
knee pain

NICE: Jinks et al 2004

# Please relax your knees now!


# Limitations of Static Imaging


Cannot capture load-
dependent knee mechanics

Delayed diagnosis and
treatment

Medial meniscus posterior horn movement in normal and horizontal tear conditions

Adapted from Lim et al., CARTILAGE. 2025

# Current Dynamic Solutions

Lack repeatability

Too complex and expensive for
wide adoption

WB-MRI weight-bearing MRI Bruno, F et al (2018). Weight-bearing
MRI of the knee: a review of advantages and limits.

# “Current knee MRIs are not representative of the pathophysiologicaljoint”


Advanced_MRI. (2020, February 10). Dynamic MRI of knee [Video]. YouTube. https://www.youtube.com/shorts/Py1L6jhOAnA

Simple, accessible and MRI-safe device; OurAims

Knee loading and positioning; OurAims; Simple, accessible and MRI-safe device

Clear clinical indications; Simple, accessible and MRI-safe device; OurAims; Knee loading and positioning

# Project Schedule

Oct 2025

Clinical scoping
and ideation

# Project Schedule

Oct 2025

Clinical scoping
and ideation

Dec 2025

Concept and
design selection

# Project Schedule

Oct 2025

Clinical scoping
and ideation

Dec 2025

Concept and
design selection

Jan 2026

Detail design and
simulation

# Project Schedule

Oct 2025

Clinical scoping
and ideation

Dec 2025

Concept and
design selection

Feb 2026

Prototype
fabrication,
testing, and Iteration

Jan 2026

Detail design and
simulation

# Design Considerations

ClinicalAdaptibility

Safe motion and loading limit

Set-up and scan time

# Design Considerations

MRI Constraints; Jacob’s Knee

Knee coil availability

Bore spatial constraints

MRI-safe Technology

# Device Modules


Loading Component | Movement Component

## Loading Crew

Movement Crew; Amy; Jacob; Hannah; Ben; Sheena; Leo; Belle; Tayeb

# Loading Component


Walking-like compression
generated through
resistance bands

Push against backplate for
standardising loading

# Movement Component


Stable support at
multiple knee angles

Patient-controlled rope
system

Easy set-up

## Risk Management & Contingency Planning


### MRI Incompatibility

Solutions:

Only non-ferromagnetic
materials

Prescan validation
checks

## Risk Management & Contingency Planning


### Patient Discomfort

Solutions:

Padding

Patient tunable load &
geometry

## Risk Management & Contingency Planning


### Mechanical Failure

Solutions:

Replaceable parts

Over 10 prototypes to be
tested

# Project Schedule

Oct 2025; Clinical scoping and ideation; Dec 2025; Concept and design selection; Feb 2026; Prototype fabrication, testing, and Iteration; Jan 2026; Detail design and simulation; Mar 2026; Healthy volunteer testing

# HealthyVolunteerTesting


# Future Directions

multiple angles; moving knee

Produce radiologist/radiographer
training materials

Achieve dynamic loading across

Generate functional MRI video of a

# “We must move away from static imaging of dynamic joints”

- NHS Orthopaedic Surgeon

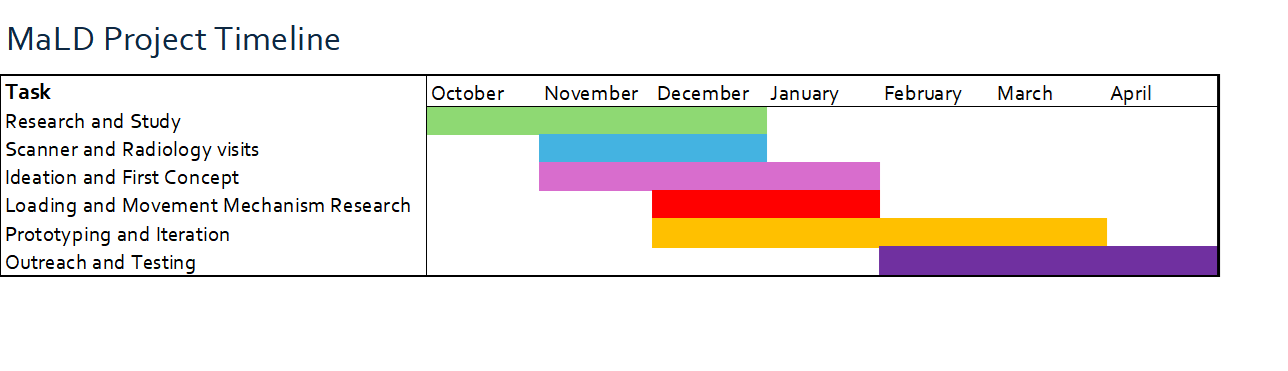
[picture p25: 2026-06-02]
Project timeline gantt chart 2025 2026.png

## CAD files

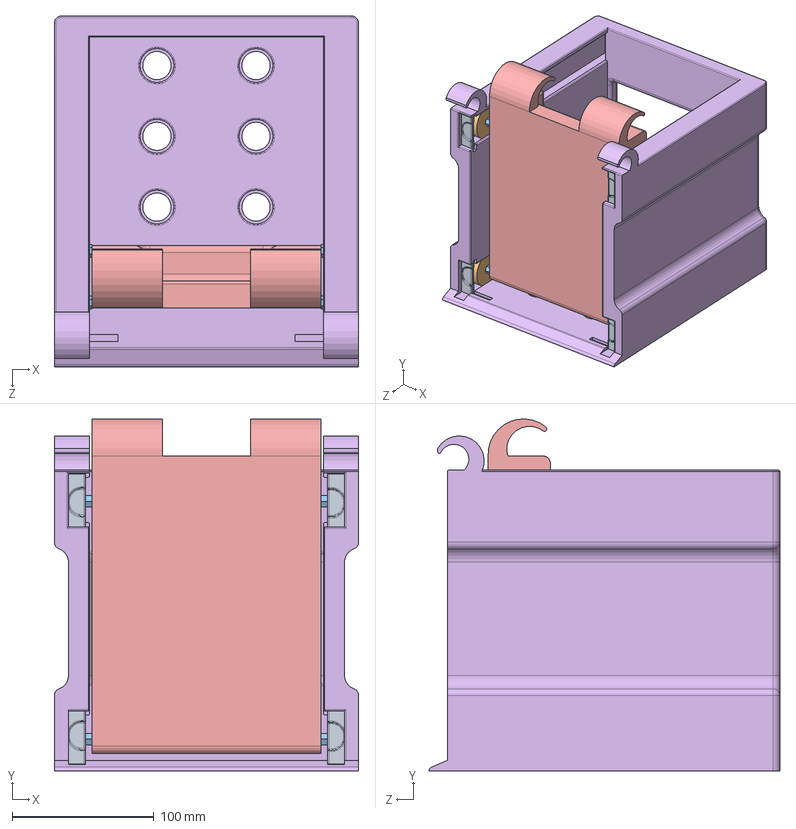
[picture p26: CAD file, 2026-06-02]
CAD files/Loading Component/Loading assembly.SLDASM
215.0 x 248.7 x 248.0 mm
Backplate
Footplate
wheel connector x 8
wheel stopper x 8
wheel 075 x 8
carriage stopper x 4

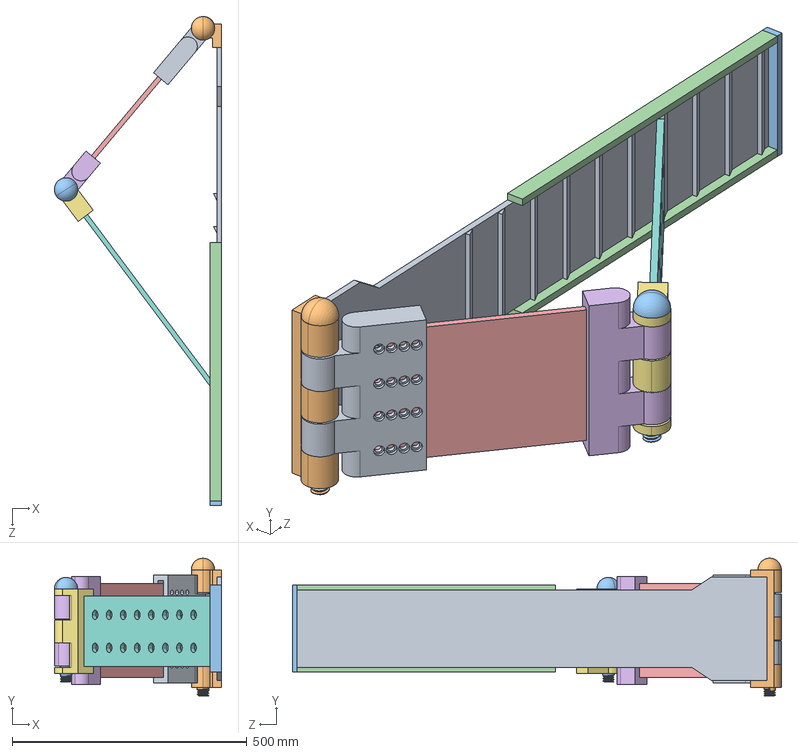
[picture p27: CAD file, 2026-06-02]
CAD files/Movement Component/assembly of part.STEP
356.2 x 293.0 x 1040.5 mm
Base plate
basecap for hinge
back rail along base plate
Side rails along base plate x 2
Thigh plate
thigh plate cap for base hinge
calf plate cap
calf plate
thigh plate cap for calf hinge
baseto thigh screw
Calf to thigh screw

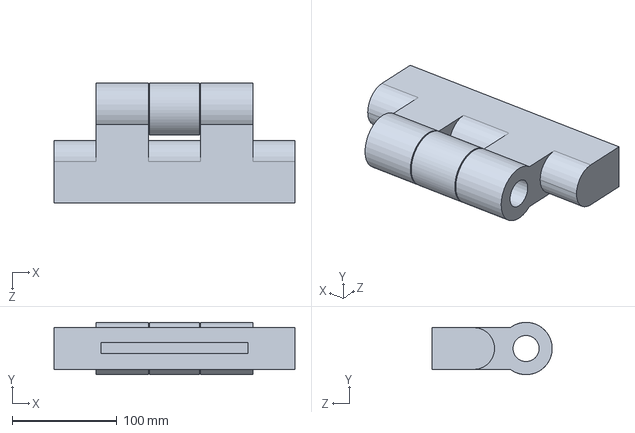
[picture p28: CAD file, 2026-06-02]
CAD files/Movement Component/calf plate cap for thigh hinge.SLDPRT
230.0 x 50.0 x 115.0 mm

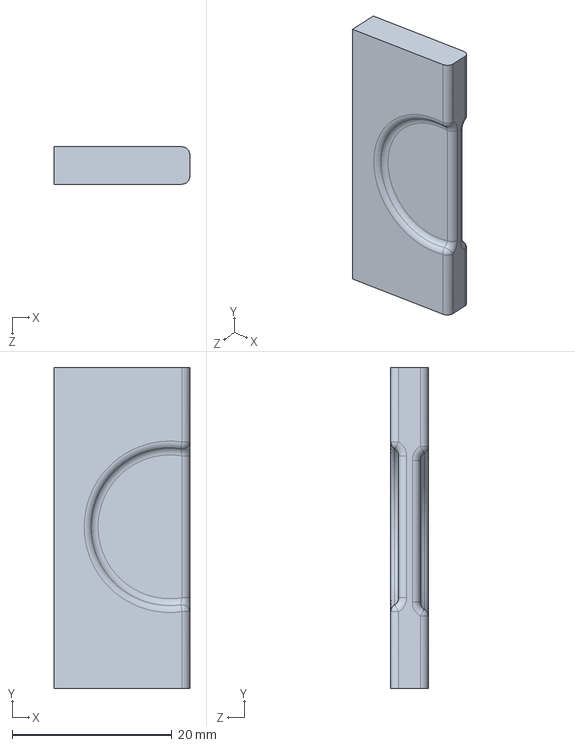
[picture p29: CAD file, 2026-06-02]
CAD files/Loading Component/carriage stopper.SLDPRT
17.0 x 40.2 x 4.70 mm

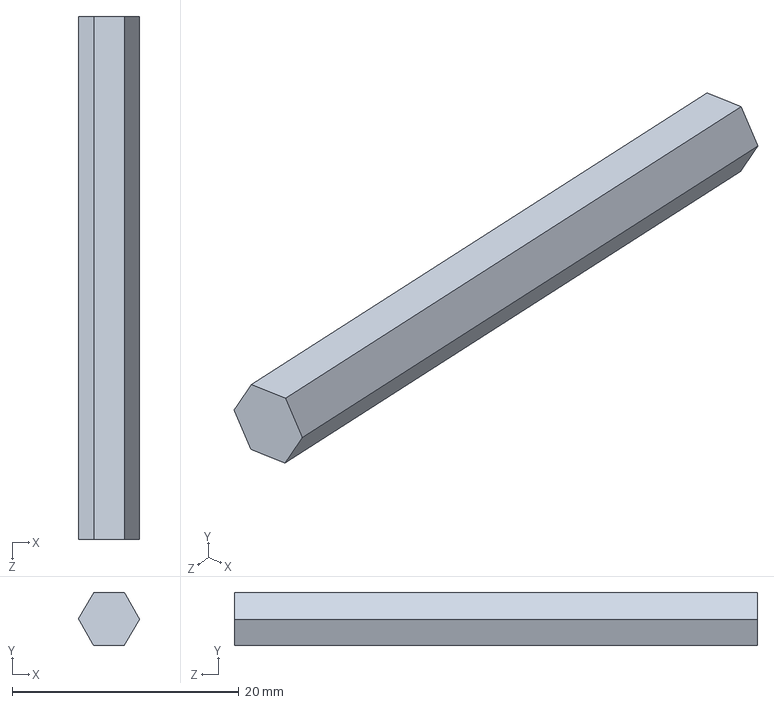
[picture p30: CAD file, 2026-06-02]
CAD files/Loading Component/wheel connector.SLDPRT
5.40 x 4.71 x 46.1 mm

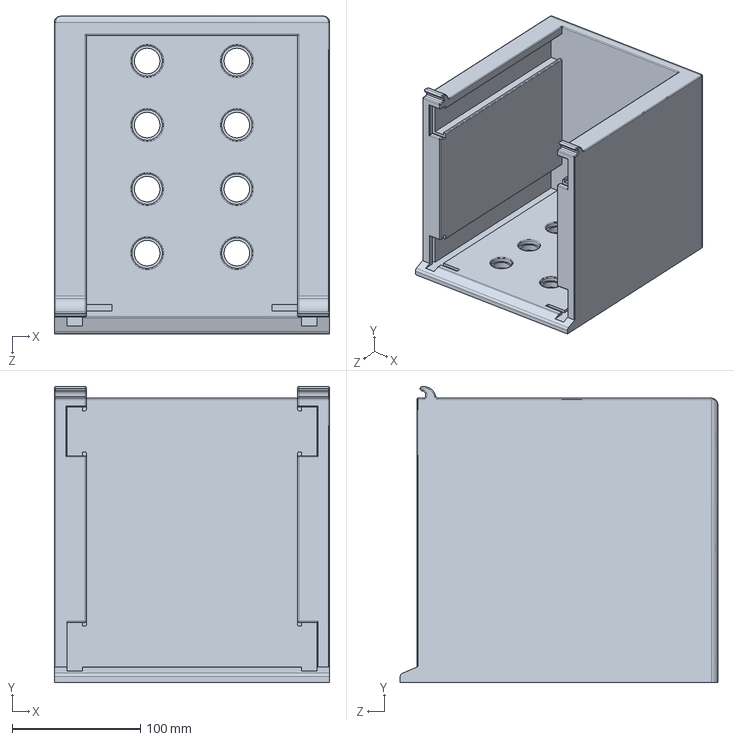
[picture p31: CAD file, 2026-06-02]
CAD files/Movement Component/Footplate for loading.SLDPRT
215.0 x 231.1 x 248.0 mm

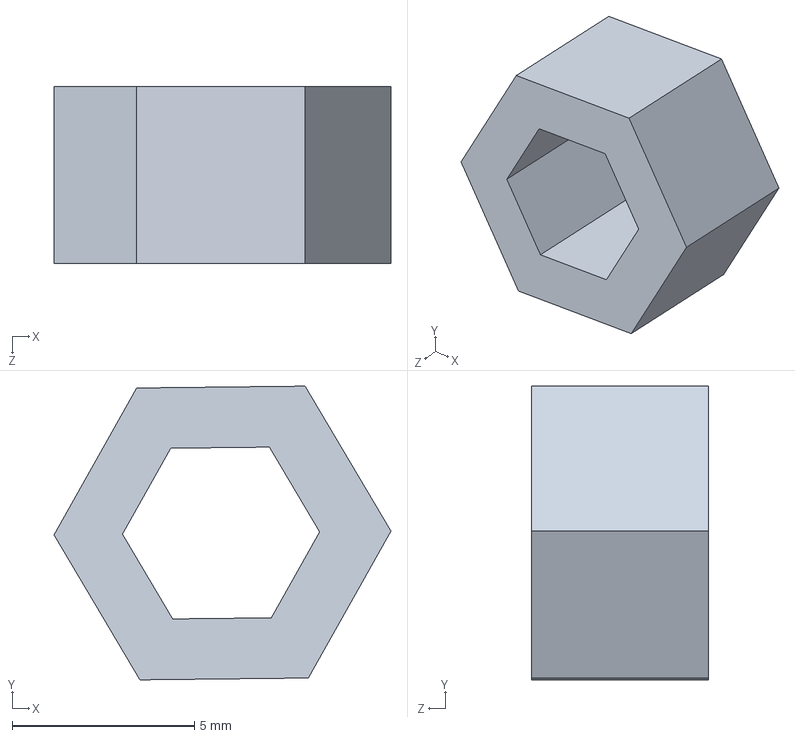
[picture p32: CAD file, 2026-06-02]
CAD files/Loading Component/wheel stopper.SLDPRT
9.24 x 8.05 x 4.85 mm

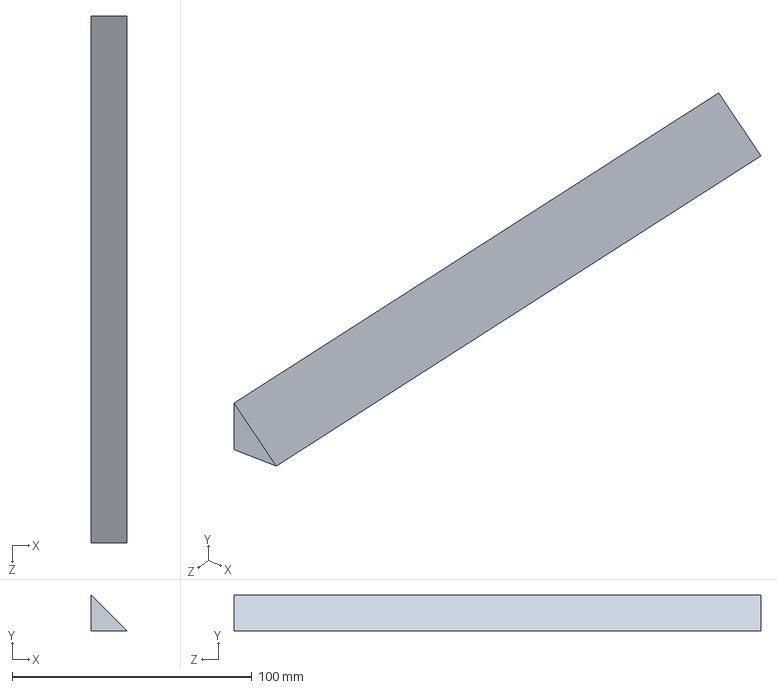
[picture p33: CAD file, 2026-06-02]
CAD files/Movement Component/Rungs on base plate.SLDPRT
15.0 x 15.0 x 220.0 mm

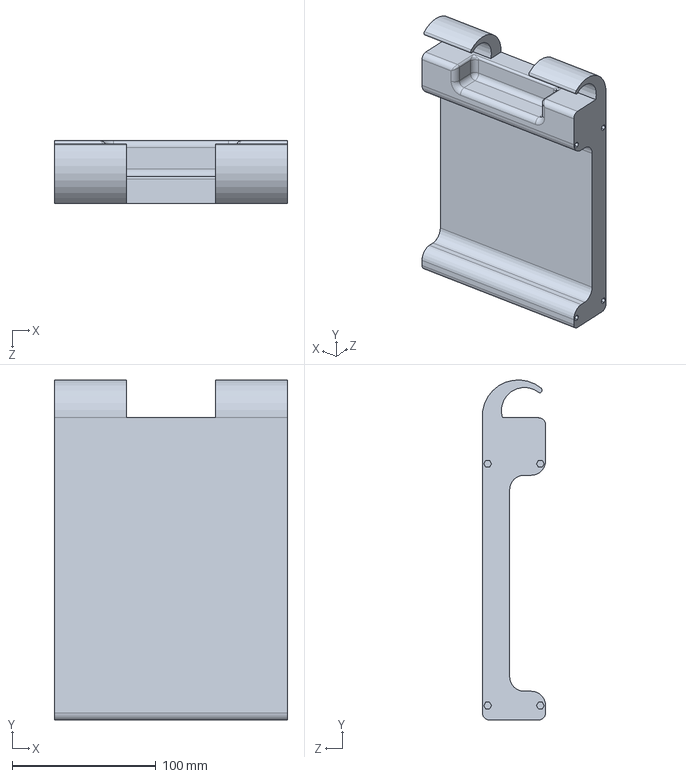
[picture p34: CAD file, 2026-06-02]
CAD files/Loading Component/Footplate.SLDPRT
162.0 x 236.2 x 44.0 mm

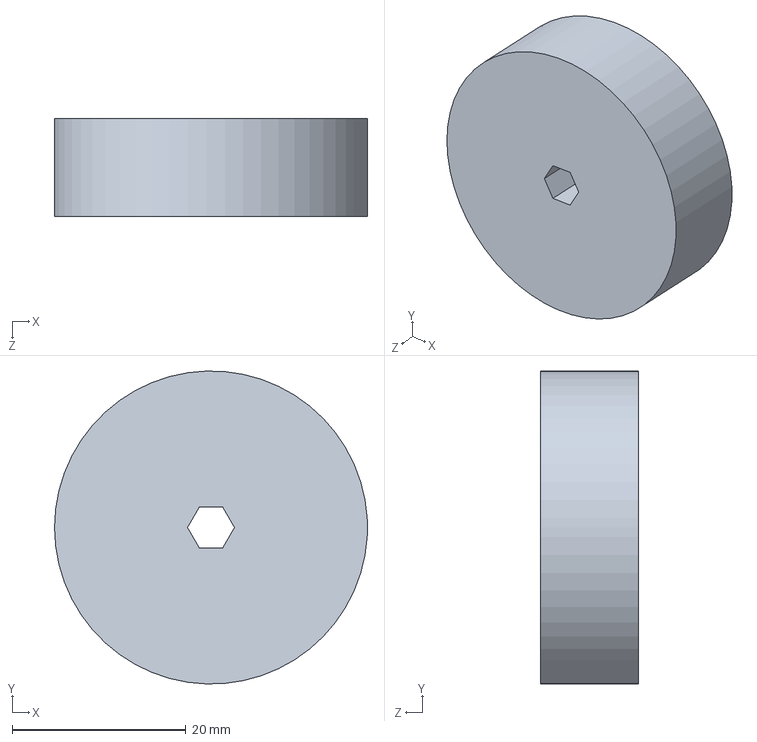
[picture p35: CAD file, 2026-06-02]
CAD files/Loading Component/wheel 075.SLDPRT
36.0 x 36.0 x 11.2 mm

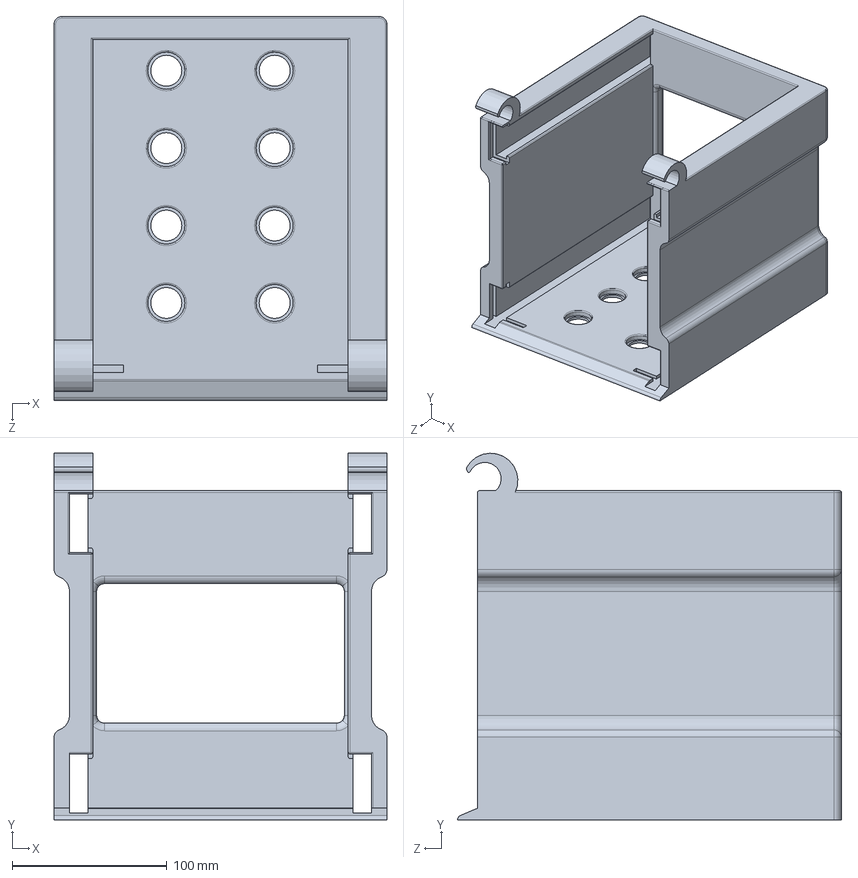
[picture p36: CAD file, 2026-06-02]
CAD files/Loading Component/Backplate.SLDPRT
215.0 x 236.8 x 248.0 mm

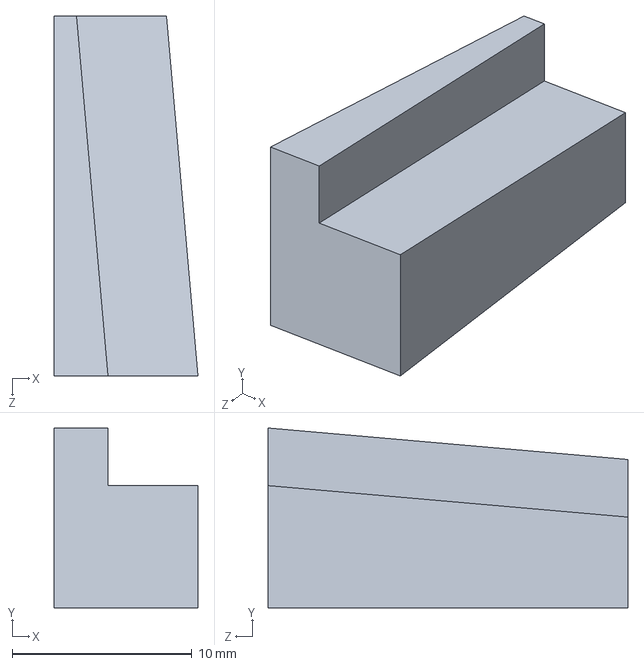
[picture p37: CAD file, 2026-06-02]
CAD files/Movement Component/door stp.SLDPRT
8.00 x 10.0 x 20.0 mm

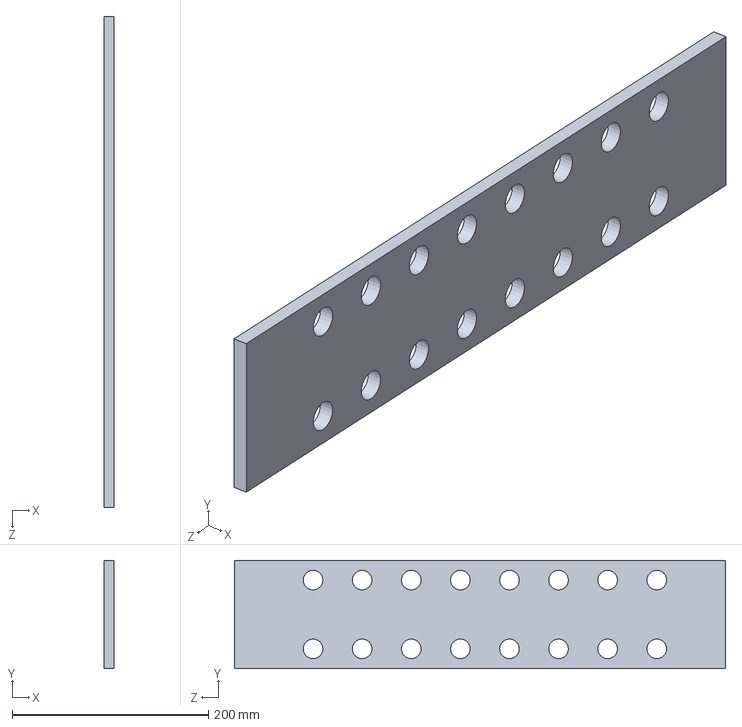
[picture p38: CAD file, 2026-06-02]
CAD files/Movement Component/calf plate.SLDPRT
10.0 x 110.0 x 500.0 mm

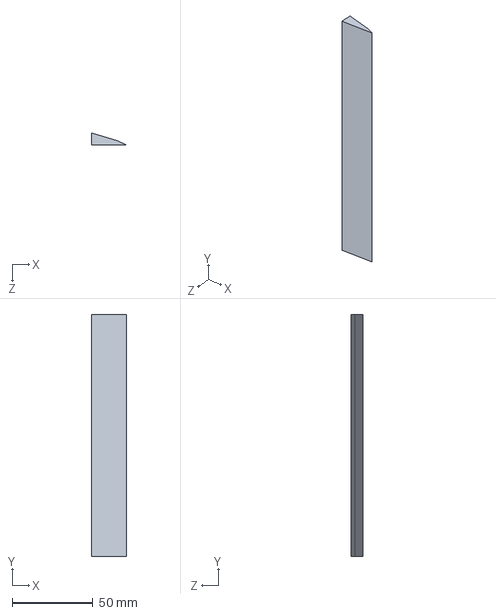
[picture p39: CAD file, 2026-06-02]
CAD files/Movement Component/notches for base plate.SLDPRT
21.8 x 150.0 x 7.50 mm

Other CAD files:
CAD files/Movement Component/Base plate.SLDPRT
CAD files/Movement Component/Cap for the end of the calf plate.SLDPRT
CAD files/Movement Component/Thigh plate.SLDPRT
CAD files/Movement Component/Jump rope handle.3mf
CAD files/Loading Component/makeProjectedPlanarWire.x_t
CAD files/Movement Component/Calf to thigh screw.SLDPRT
CAD files/Movement Component/Screws for attaching footpedal.SLDPRT
CAD files/Movement Component/Screws for changing thigh plate.SLDPRT
CAD files/Movement Component/Side rails along base plate.SLDPRT
CAD files/Movement Component/assembly of part.SLDASM
CAD files/Movement Component/back rail along base plate.SLDPRT
CAD files/Movement Component/basecap for hinge.SLDPRT
CAD files/Movement Component/baseto thigh screw bottom.SLDPRT
CAD files/Movement Component/baseto thigh screw top.SLDPRT
CAD files/Movement Component/baseto thigh screw.SLDPRT
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

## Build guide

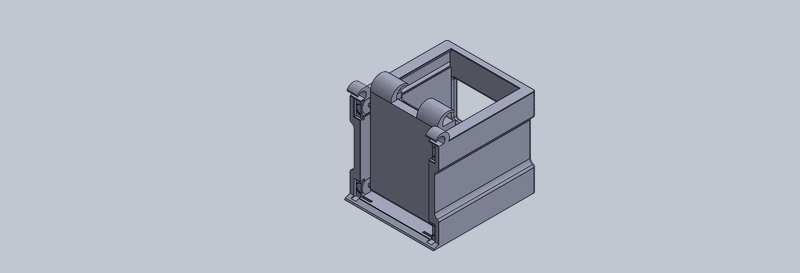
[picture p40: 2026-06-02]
CAD files/Loading Component/loadingassemblygif.gif

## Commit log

2026-06-02 Enhance README with detailed project overview and features
    Expanded project description and added details about the device's features, concept, materials, and fabrication methods.
2026-06-02 Add files via upload
    Solidworks CAD files and Assemblies for Loading Component
    [Backplate.SLDPRT, Footplate.SLDPRT, Loading assembly.SLDASM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]
